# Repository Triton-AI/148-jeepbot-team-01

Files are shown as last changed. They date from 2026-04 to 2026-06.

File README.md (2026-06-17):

# 🚗 JeepBot | ECE/MAE 148 — Team 01

PowerWheels Jeep converted into a modular robotics platform for autonomous vehicle development, hardware integration, and controls experimentation.

Developed through UC San Diego ECE/MAE 148 in collaboration with Triton AI.

---

## ⚡ Overview

JeepBot is designed as a scalable and reproducible robotics platform combining:

- Raspberry Pi 5 for onboard computing and control
- VESC motor controllers for vehicle actuation
- OAK-D cameras for computer vision
- LiDAR and additional sensors for autonomous navigation
- ExpressLRS controller integration for manual control and testing

The project combines electrical integration, embedded systems, mechanical design, and software development.

---

## 🔧 Hardware Development

A major focus of this project was creating a clean, organized, and maintainable electronics architecture.

The system went through multiple hardware iterations:

### Version 1

- Initial full-scale architecture
- Designed around 5 VESC motor controllers
- More complex wiring system supporting multiple independent vehicle subsystems

### Version 2

- Simplified architecture using 2 VESC motor controllers
- Reduced wiring complexity
- Improved reliability and maintainability
- Redesigned to make the platform easier for future robotics students to reproduce, debug, and expand

The Version 2 redesign prioritizes accessibility while keeping the system expandable for future development.

Documentation for both versions:

`docs/version1/`

`docs/version2/`

---

## 📡 ELRS Controller Integration

The project includes development of a RadioMaster ExpressLRS controller interface for JeepBot testing and operation.

This allows manual control and testing during the development process while supporting future autonomous features.

Documentation and implementation:

`docs/elrs_controller/`

---

## 🧠 System Architecture

Control pipeline:

ExpressLRS Controller  
↓  
Receiver  
↓  
Raspberry Pi 5  
↓  
VESC Motor Controllers  
↓  
Motors / Steering  

Sensor pipeline:

OAK-D Cameras + LiDAR  
↓  
Raspberry Pi 5  
↓  
Autonomous Processing Stack  

---

## 📂 Repository Structure

CAD/

- electronics/
- mechanical/
- sensors/

docs/

- setup/
- version1/
- version2/
- elrs_controller/

src/

- jeepbot/
- camera/
- tests/

---

## 📚 Documentation

Technical documentation includes:

- Wiring diagrams
- Hardware revisions
- Raspberry Pi setup
- DepthAI/OAK-D setup
- ELRS controller integration
- Mechanical and electrical references

Main documentation:

`docs/`

---

## 🚧 Current Development Status

Completed:

✅ Vehicle hardware assembly  
✅ Electronics mounting and organization  
✅ VESC setup and configuration  
✅ Hardware architecture redesign (Version 1 → Version 2)  
✅ Documentation consolidation  

Ongoing:

- Continued software integration
- Sensor integration and testing
- Autonomous control development
- Future expansion toward the original 5-VESC architecture

---

## 👥 Team

ECE/MAE 148 — UC San Diego  
Triton AI

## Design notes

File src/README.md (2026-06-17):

# Source Code

This folder contains the main JeepBot software components.

## Structure

- `camera/`  
  Camera and depth perception code (OAK-D / DepthAI).

- `jeepbot/`  
  Vehicle control software including:
  - VESC control
  - controller interfaces
  - training scripts
  - perception integration
  - web interface tools

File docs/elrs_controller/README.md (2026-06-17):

# JeepBot ELRS Controller

Turn a RadioMaster **ExpressLRS** radio into a plug-and-play **USB joystick** for
DonkeyCar. An Arduino Leonardo reads the ELRS receiver's serial stream, filters and
decodes every stick / switch / button, and re-presents the whole thing to a Raspberry
Pi as a standard USB HID game controller at `/dev/input/js0`.

```
RadioMaster TX  ──2.4GHz──▶  RP4TD RX  ──serial @115200──▶  Arduino Leonardo  ──USB HID──▶  Raspberry Pi / DonkeyCar
```

## 📖 Setup guide

**Full step-by-step documentation:**
👉 **https://<your-username>.github.io/JeepBot-ELRS-Controller/**

It covers flashing the transmitter and receiver (ELRS Configurator v4.0.1, binding
phrase `JEEPBOT`), wiring the receiver to the Leonardo, building the firmware, the
DonkeyCar integration, the full channel map, and troubleshooting.

## Quick start

```bash
git clone https://github.com/<your-username>/JeepBot-ELRS-Controller.git
cd JeepBot-ELRS-Controller

pio run                      # build for the Arduino Leonardo
pio run --target upload      # flash it (board connected over USB)
```

All required libraries (`Joystick`, `FUTABA_SBUS`, `Streaming`) are vendored in
`lib/`, so there is nothing else to install beyond [PlatformIO](https://platformio.org/).

## Repo layout

| Path | What it is |
|---|---|
| `src/main.cpp` | Firmware: SBUS → filtered USB-HID joystick |
| `src/utils/` | Rolling-average `SBusTracker` helper |
| `lib/` | Bundled Arduino libraries (Joystick, FUTABA_SBUS, Streaming) |
| `donkeycar_joystick/my_joystick.py` | DonkeyCar controller part that maps the joystick to driving actions |
| `platformio.ini` | Build config (targets `leonardo`) |
| `docs/` | The setup-guide website (served by GitHub Pages) |

## Debug logging

Serial output is **off by default**, because on the Leonardo the debug Serial can
conflict with the USB-HID interface. To watch raw channel values while testing,
enable the build flag — then turn it back off for normal use:

```ini
[env:leonardo]
build_flags = -DDEBUG_LOG
```

## Hardware

- RadioMaster Pocket (internal 2.4 GHz, EdgeTX) — transmitter
- RadioMaster RP4TD True-Diversity 2.4 GHz — receiver
- Arduino Leonardo (ATmega32U4; USB-HID capable — an Uno will **not** work)
- Raspberry Pi running DonkeyCar

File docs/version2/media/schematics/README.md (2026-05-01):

# Schematics

This folder contains system-level and subsystem schematics for Version 2.

## Files
- system_schematic_v2.png → main system diagram

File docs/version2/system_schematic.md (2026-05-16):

# System Schematic

## Overview
This diagram represents the full system architecture, including power, control, actuation, and sensors.

---

## Interactive Version
🔗[Open Editable Schematic (SharePoint)](https://ucsdcloud-my.sharepoint.com/:u:/r/personal/hrubim_ucsd_edu/Documents/Drawing.vsdx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)

---

## Static View

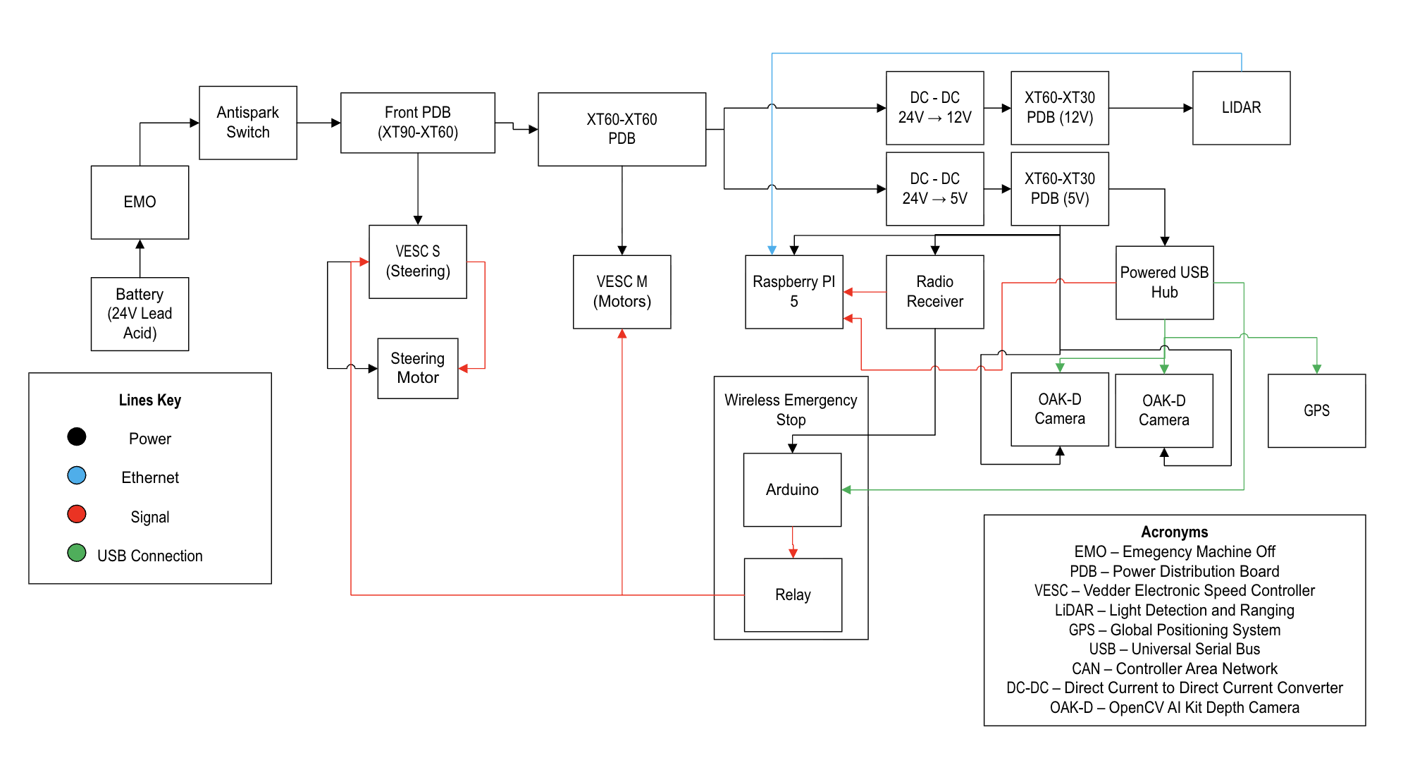
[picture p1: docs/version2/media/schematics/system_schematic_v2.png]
System Schematic


---

## Static With Components

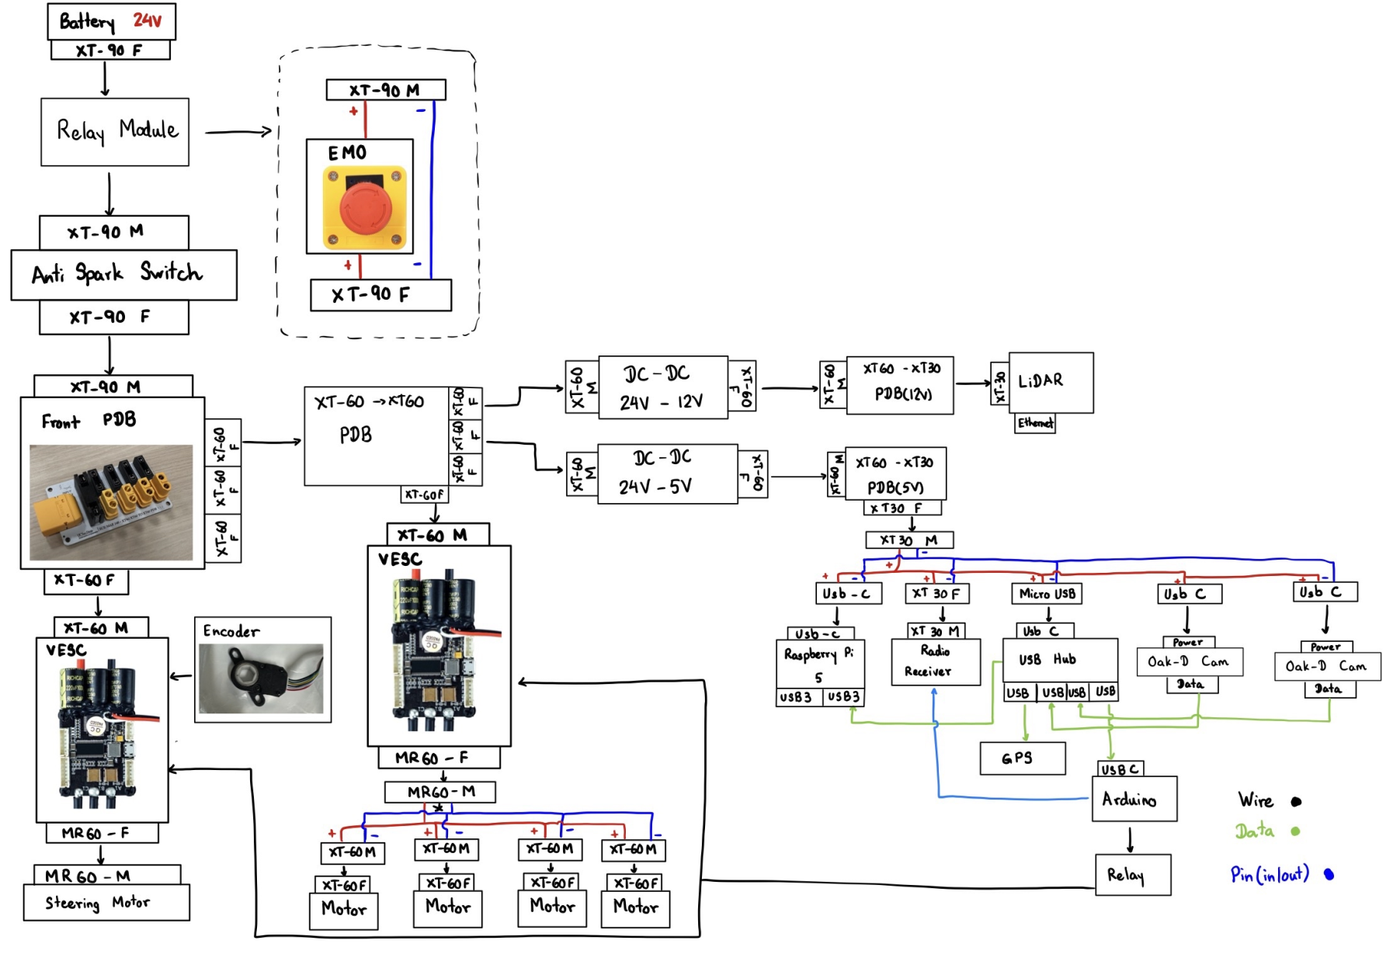
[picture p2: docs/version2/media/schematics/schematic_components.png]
System Schematic With Components


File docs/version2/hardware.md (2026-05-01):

# Hardware

## Core Components

### Power System
- 24V Lead Acid Battery
- EMO (Emergency Stop switch)
- Antispark Switch
- Power Distribution Board (PDB)

### Motor Control
- VESC (Motor Controller)
- VESC (Steering Controller)

### Compute
- Raspberry Pi 5
- Arduino (safety + relay control)

### Sensors
- 2x OAK-D Cameras
- LiDAR
- GPS Module

### Supporting Components
- DC-DC converters (24V → 12V, 5V)
- Powered USB Hub
- Wiring harness (12 AWG power lines)

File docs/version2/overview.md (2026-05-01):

# Overview

This system is a modified PowerWheels Jeep platform designed for robotics development.

The architecture is centered around a 24V power system with distributed control, sensing, and computation. The system integrates motor control (VESC), onboard computing (Raspberry Pi 5), sensor fusion (OAK-D cameras, LiDAR, GPS), and a safety layer with emergency stop functionality.

## High-Level Flow

Battery → EMO → Antispark → PDB → Subsystems

- Power is distributed to:
  - Motor controllers (VESC)
  - DC-DC converters (12V and 5V)
- Raspberry Pi acts as the central compute node
- Arduino handles safety and emergency stop logic
- Sensors feed data through USB and communication interfaces

This modular architecture allows easy debugging, expansion, and subsystem isolation.

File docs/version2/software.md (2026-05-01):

# Software

## Architecture

The system is structured around a central processing node (Raspberry Pi) and modular subsystems.

## Main Components

- Camera module:
  - Depth sensing
  - RGB capture
  - Dual OAK-D support

## Execution

Entry point:
src/main.py

Modules:
- camera/
- tests/

## Responsibilities

- Raspberry Pi:
  - Sensor processing
  - Decision making

- Arduino:
  - Emergency stop logic
  - Relay control

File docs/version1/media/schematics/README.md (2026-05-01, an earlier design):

# Schematics

This folder contains system-level and subsystem schematics for Version 1.

## Files
- system_schematic_v1.png → main system diagram

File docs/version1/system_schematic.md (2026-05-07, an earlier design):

# System Schematic (Version 1)

## Overview
This diagram represents the initial system architecture before simplification.

---

## Interactive Version
🔗 [Open Editable Schematic (SharePoint)](https://ucsdcloud-my.sharepoint.com/:u:/g/personal/hrubim_ucsd_edu/IQCxfeaB-xmnSrFH_fL8HkIkAejA7a_xhp8tK149ex-IXM8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)

---

## Static View

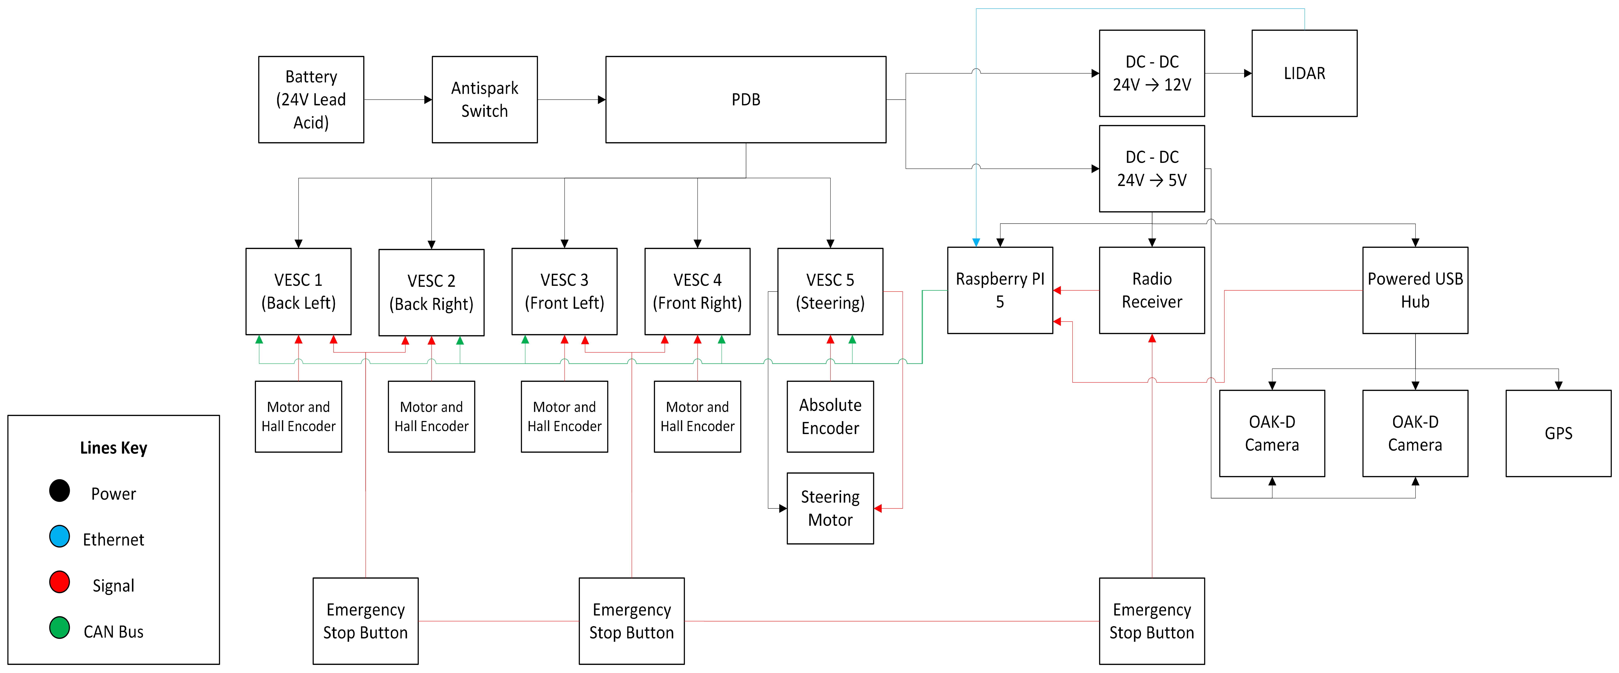
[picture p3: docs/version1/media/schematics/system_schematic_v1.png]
System Schematic


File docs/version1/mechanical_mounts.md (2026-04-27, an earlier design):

## 1. Overview

The mechanical system of the robot consists of custom-designed mounts used to securely attach sensors such as cameras and LiDAR to the jeep platform.

These mounts ensure:

- Stable sensor positioning  
- Consistent data collection  
- Proper alignment for perception systems  

Detailed CAD models, component breakdowns, and step-by-step installation instructions are provided in the full mounts documentation.

---

## 2. Full Mount Documentation

The complete mechanical design and installation guide is available in the following document:

**Document:** Jeepbot Mount Documentation  
**Author:** Keenai Braun  

Includes:

- CAD models for all mounts  
- Hardware requirements (screws, fasteners, components)  
- Detailed installation steps  
- Mounting configurations and variations  

---

## 3. Mounts Included in the System

### Front Camera Mount
- Holds the forward-facing OAK-D camera  
- Aligns with vehicle driving direction  

### Rear Camera Mounts (Two Configurations)

**Bar Mount**
- Attaches camera to structural bar  
- Uses clamp-based support  

**Ridge Mount**
- Positions camera higher on trunk  
- Improves rear perception  

### LiDAR Mount
- Secures LiDAR on top of vehicle  
- Enables 360° environmental scanning  

---

## 4. Mount Design Considerations

All mounts are designed to:

- Maintain rigid attachment during motion  
- Minimize vibration  
- Ensure correct orientation and field of view  
- Allow access for wiring and connections  

---

## 5. Installation Notes

- Follow the full documentation carefully  
- Some mounts may require cutting or drilling  
- Proper alignment is critical  
- Multiple iterations may be needed for best fit

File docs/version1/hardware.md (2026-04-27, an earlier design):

## 1. Hardware Architecture Overview

The robot hardware system is organized into three main layers:

- Power layer → provides energy to all components  
- Control layer → processes commands and controls movement  
- Sensor layer → collects environmental and system data  

Power flows from the battery through the Power Distribution Board (PDB), while the Raspberry Pi acts as the central controller.

---

## 2. Battery and Main Power System

The robot is powered by a 24V lead-acid battery:

- Voltage: 24V  
- Capacity: 7Ah  

**Power path:**  
Battery → Antispark Switch → Power Distribution Board (PDB)

- Antispark switch prevents inrush current  
- PDB distributes power and provides fuse protection  

---

## 3. Power Distribution

Power from the PDB is distributed to:

- VESC motor controllers  
- DC-DC converters  
- Onboard electronics  

**Voltage regulation:**

- 24V → motors (via VESCs)  
- 24V → 12V → LiDAR  
- 24V → 5V → Raspberry Pi, USB hub, sensors  

---

## 4. Wiring

Silicone insulated stranded wire is used for:

- Flexibility  
- Heat resistance  
- Vibration tolerance  

**Wire gauges:**

- 10 AWG → battery / high-current  
- 12 AWG → motors  
- 14–16 AWG → 5V electronics  
- 24 AWG → CAN bus  

---

## 5. Power Connectors

XT-series connectors are used:

- XT90 → battery  
- XT60 → distribution / converters  

Benefits:

- High current support  
- Reverse polarity protection  
- Strong connections  

---

## 6. Battery Power Cable

- 10 AWG silicone wire  
- Handles highest current in system  
- Connects battery → antispark → PDB  

---

## 7. Power Distribution Board (PDB)

The PDB:

- Distributes power to all subsystems  
- Connects VESCs and converters  
- Includes fuse protection  

Mounted inside the chassis.

---

## 8. Internal Wiring Layout

Connects:

- Motor controllers  
- Steering system  
- Encoders  
- Raspberry Pi  
- PDB  

Design goals:

- Minimize cable length  
- Reduce noise  
- Improve debugging access  

---

## 9. Motor Control System (VESC)

Five VESC controllers:

- VESC 1 → Back Left  
- VESC 2 → Back Right  
- VESC 3 → Front Left  
- VESC 4 → Front Right  
- VESC 5 → Steering  

Controls:

- Speed  
- Torque  
- Direction  

---

## 10. Encoder System

### Motor Encoders (Hall-effect)

- Provide rotor position  
- Connected to VESC  
- Enable precise control  

### Steering Encoder

- AS5600 magnetic sensor  
- I2C communication  
- Measures steering angle  

### Additional Encoder

- REV Through Bore Encoder  
- High-resolution rotation sensing  

---

## 11. Communication Interfaces

- CAN Bus → VESC network  
- USB → cameras, GPS (via hub)  
- I2C → steering encoder  
- Radio → RC → Pi  

---

## 12. Raspberry Pi (Main Controller)

Raspberry Pi 5 handles:

- Control logic  
- Communication with VESCs  
- Sensor data processing  

Connected to:

- CAN HAT  
- USB hub  
- Cameras  
- GPS  
- Radio receiver  

---

## 13. Sensors

- 2× OAK-D cameras → vision  
- LiDAR → mapping  
- GPS → localization  
- Encoders → motion + steering  

---

## 14. Physical Layout

- Battery → rear  
- PDB → center  
- Pi → communication hub  
- VESCs → near motors  
- Sensors → external  

Improves:

- Weight distribution  
- Wiring efficiency  
- Accessibility  

---

## 15. Emergency Stop System

- Multiple emergency stop buttons  
- Interrupt motor control signals  
- Immediately stop motion  

---

## 16. Safety and Best Practices

- Disconnect battery before working  
- Verify polarity  
- Avoid shorts on PDB  
- Secure all connections  
- Keep emergency stops accessible  

---

## 17. Current Limitations

- Wiring organization can improve  
- Cable management incomplete  
- Some components exposed  
- Steering encoder not fully integrated  
- Layout may change during development

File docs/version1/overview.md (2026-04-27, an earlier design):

# Documentation Overview

This documentation provides a complete overview of the Jeep robot system, including hardware, software, control, and system integration.

Each section is organized to guide the reader from a high-level understanding of the system to detailed implementation and troubleshooting.

## Sections

### Overview
Provides a general introduction to the robot system, including its purpose, main components, and overall architecture.

### Current Status
Describes the current state of the project, including what is working, what is incomplete, and known issues.

### Hardware
Details all physical components of the system, including power distribution, wiring, motor controllers, sensors, and connections.

### Mechanical (Mounts)
Documents all mechanical structures and 3D-printed mounts used to hold sensors and components in place.

### Software & Control
Covers the software architecture, Raspberry Pi setup, communication with VESC controllers, and control logic.

### Setup Guide
Step-by-step instructions for setting up and running the system from scratch.

### Troubleshooting
Lists common issues, known problems, and solutions to help debug the system.

### Media
Contains images and visual documentation of the robot, components, wiring, and system setup.

### Bill of Materials (BOM)
Lists all components used in the project, including parts, specifications, and references.

### Progress & Logs
Tracks the development timeline, key milestones, and ongoing updates to the project.

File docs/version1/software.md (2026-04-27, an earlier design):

## 1. Software Overview

The robot uses a Raspberry Pi 5 as the main computer responsible for system control, communication, and data processing.

The software system handles:

- Receiving user input (RC controller / teleoperation)  
- Sending commands to motor controllers (VESCs)  
- Reading and processing sensor data  
- Managing communication between system components  

This architecture enables centralized control while remaining modular for future upgrades.

---

## 2. Control Flow

**Primary control path:**

User Input → Radio Receiver → Raspberry Pi → CAN Bus → VESC → Motors

**Sensor data flow:**

Sensors → Raspberry Pi → Data Processing / Logging

The Raspberry Pi translates inputs into motor commands and collects sensor data.

---

## 3. Teleoperation

Teleoperation enables manual control during development.

### RC Controller (Primary Method)
RC → Receiver → Raspberry Pi → CAN → VESC → Motors

- Low latency  
- High reliability  
- No internet required  

### ROS2 Teleoperation (Future)
Laptop → WiFi → Raspberry Pi → CAN → VESC

- Integrates sensor data  
- Enables autonomy development  

### Web Dashboard (Optional)
Web → WiFi → Raspberry Pi → Motors

- Simple control interface  
- Displays sensor data  

### Strategy

- RC Controller → primary control  
- ROS2 → advanced/autonomous control  
- Web dashboard → visualization  

---

## 4. Sensor Data Handling

Connected sensors:

- OAK-D cameras  
- LiDAR  
- GPS (pending)  
- Motor encoders  

Used for:

- System monitoring  
- Data collection  
- Future autonomy  

Processing is done locally on the Raspberry Pi.

---

## 5. Running the System (Basic)

- Power on system  
- Connect to Raspberry Pi (SSH / NoMachine)  
- Run control software  
- Drive using RC controller  

*Commands will be added once finalized.*

---

## 6. Future Development

Planned improvements:

- Autonomous navigation  
- Sensor fusion  
- Obstacle detection  
- Path planning  
- Improved CAN control  
- Full Pi ↔ VESC integration

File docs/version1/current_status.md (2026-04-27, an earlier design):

## 1. Overview

The system is fully assembled mechanically but is currently non-operational due to hardware and software integration issues.

---

## 2. What Is Working

- All components are mounted on the jeep  
- Four drive VESCs are fully configured and tested with motors and encoders  
- CAN communication between VESCs works when tested independently (daisy-chain)  
- Raspberry Pi is mounted and includes a CAN HAT  
- Encoder mounts are properly installed and functional  
- Motor encoders are wired and working  

---

## 3. What Is Not Working

### 3.1 Power System
- The antispark switch is broken and does not interrupt power  
- The system powers on immediately when the battery is connected, which is unsafe  
- One of the PDB fuses is missing or broken  
- This issue is related to a broken connector in the LiDAR power line  
- Path affected: PDB → 12V DC-DC converter → LiDAR  
- The corresponding PDB output does not activate (no indicator light)  
- LiDAR is not receiving power  

### 3.2 Control and Movement
- The robot does not move  
- Raspberry Pi is not yet integrated with the VESC network for control  
- CAN communication between the Raspberry Pi and VESC network has not been implemented  
- Motor controllers work individually but are not integrated into the full system  

### 3.3 Steering System
- Steering VESC (VESC 5) is installed and connected  
- Steering encoder is not connected to the VESC  
- Current encoder is not directly compatible with VESC input  
- Alternative integration or different encoder is required  
- Steering is not functional due to lack of encoder feedback  

### 3.4 Sensors
- Front and rear cameras are mounted but not connected to the USB hub  
- Front camera needs a longer USB cable  
- Rear camera is not connected  
- LiDAR is installed but not powered  
- GPS module is not installed  

### 3.5 Wiring and Integration
- 5V DC-DC converter cables are too short  
- 5V output not connected to Raspberry Pi or USB hub  
- CAN wiring between VESCs is complete  
- CAN not connected to Raspberry Pi CAN HAT  
- USB connections incomplete  

### 3.6 Emergency and Safety
- Emergency stop system is not connected  
- No hardware-level shutdown mechanism  
- System powers on immediately when battery is connected  
- This is a critical safety risk  

### 3.7 Software
- Raspberry Pi was reflashed — current state uncertain  
- Camera setup may need reconfiguration  
- VESC CAN control not implemented  
- Control software incomplete  
- System environment not validated  

---

## 4. Main Blocking Issues

- Broken antispark switch (unsafe power behavior)  
- No emergency stop system (no safe shutdown)  
- No CAN communication (Pi → VESCs)  
- Steering encoder not connected / incompatible  
- LiDAR power failure (PDB fuse / connector issue)  
- Critical 5V and USB connections incomplete

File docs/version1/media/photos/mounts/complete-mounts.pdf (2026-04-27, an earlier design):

## Jeepbot: Mount Documentation

## Keenai Braun

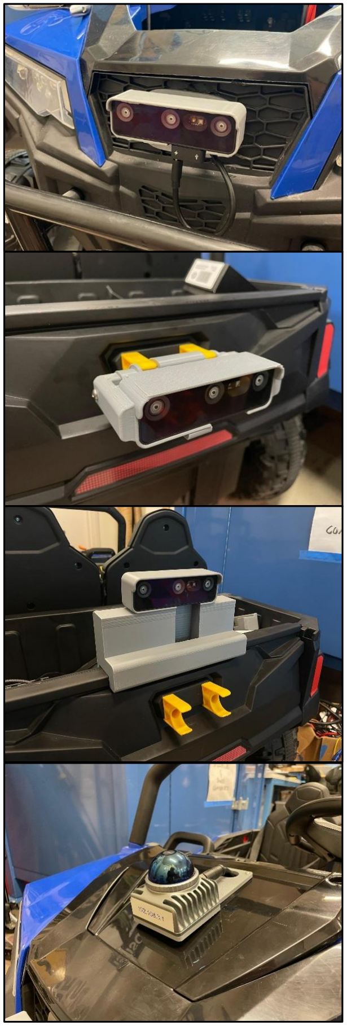
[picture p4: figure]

2 | P a g e

Table of Contents

### 1 MOUNTS | 3

### 1.1 OVERVIEW | 3 1.2 FRONT CAMERA MOUNT | 7 1.3 REAR CAMERA MOUNTS | 15

1.3.1 BAR MOUNT - VARIATION 1 | 15
1.3.2 RIDGE MOUNT - VARIATION 2 | 21

### 1.4 LIDAR MOUNT | 23

Table of Figures

Figure 1: CAD Assembly of Front Camera Mount | 3
Figure 2: CAD Assembly of Rear Camera Mount (Bar Mount - Variation 1) | 4
Figure 3: CAD Assembly of Rear Camera Mount (Ridge Mount - Variation 2) | 5
Figure 4: CAD of LIDAR Mount | 6
Figure 5: Front Camera Mount | 7
Figure 6: Front Camera Cap | 8
Figure 7: Dual Mount – Camera and PDB | 9
Figure 8: Rear Camera Mount | 15
Figure 9: Trunk Bar | 16
Figure 10: Trunk Bar Support | 17
Figure 11: Ridge Mount | 21
Figure 12: LIDAR Mount | 23

Revision History

Author | Revision | Comment
Keenai Braun | 15th March, 2026 (Rev. 1.0) | Initial Draft
Keenai Braun | 17 th March, 2026 (Rev. 2.0) | Final submission

## 1 Mounts

There are a total of three external mounts on the Jeepbot – front camera, rear camera, and LIDAR. The rear camera has two mounting variations: bar mount and ridge mount. In this section, you will find an overview of the four mount assemblies with the individual components that make up each one. Next, you will see the individual components per mount configuration along with the additional parts needed for each one during installation. Finally, you will see a sequence of installation steps and photos to help guide you with your installation process.

1.1 Overview

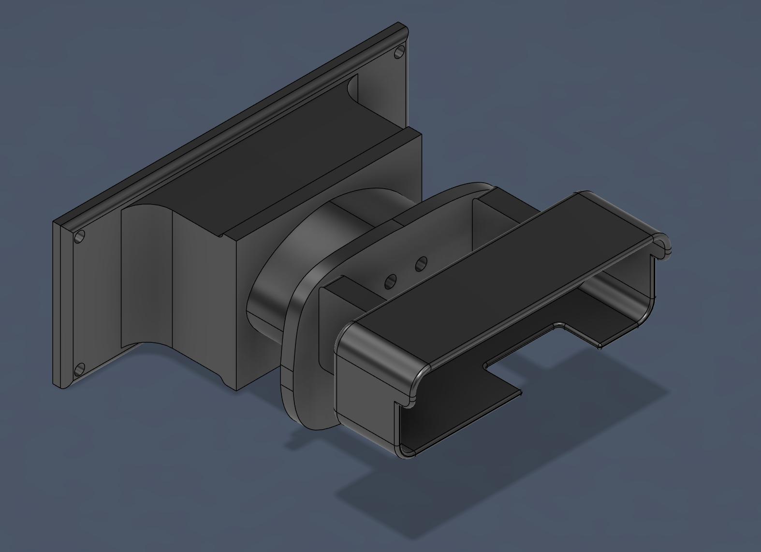
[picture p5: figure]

Figure 1: CAD Assembly of Front Camera Mount

Components
1) Front Camera Mount
2) Front Camera Cap
3) Dual Mount – Camera and PDB

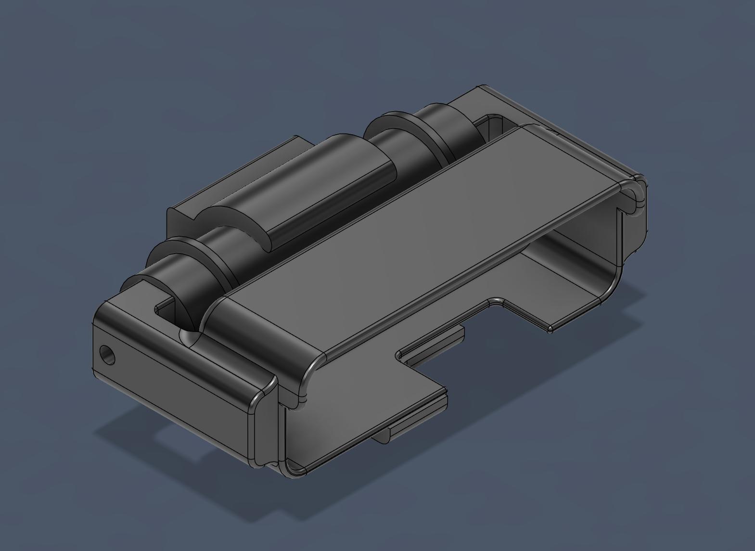
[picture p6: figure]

Figure 2: CAD Assembly of Rear Camera Mount (Bar Mount - Variation 1)

Components
1) Rear Camera Mount
2) Trunk Bar
3) Trunk Bar Support

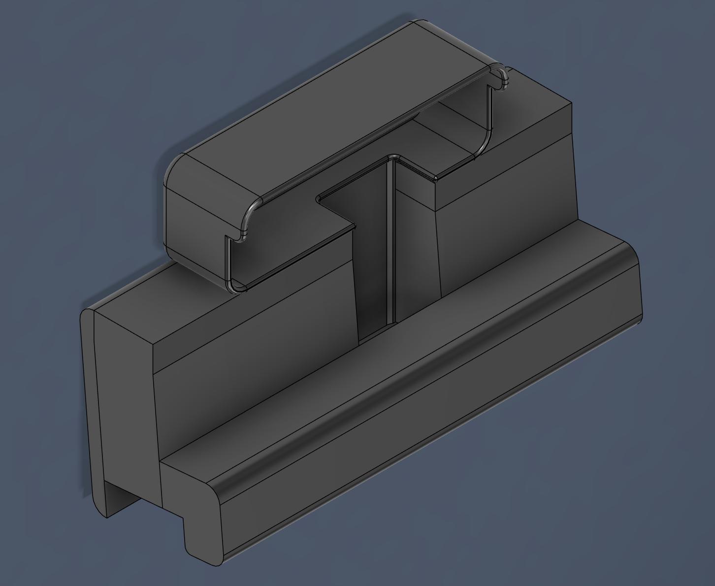
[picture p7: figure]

Figure 3: CAD Assembly of Rear Camera Mount (Ridge Mount - Variation 2)

Components

1) Ridge Mount

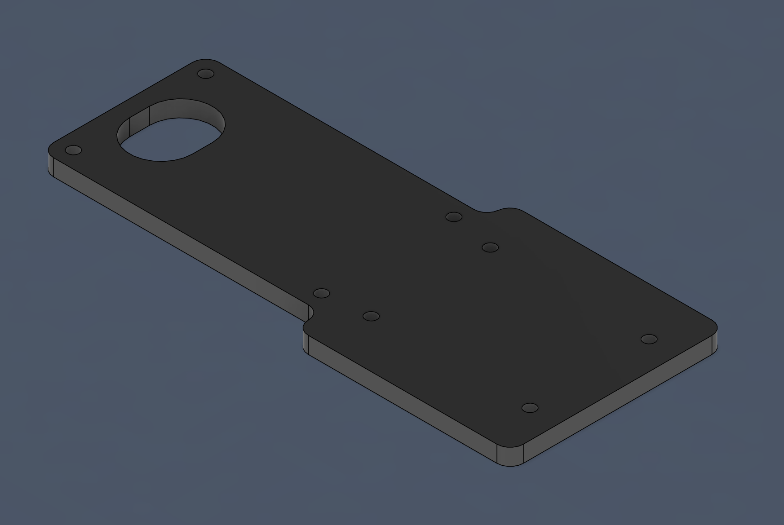
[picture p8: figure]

Figure 4: CAD of LIDAR Mount

Components

1) LIDAR Mount

1.2 Front Camera Mount

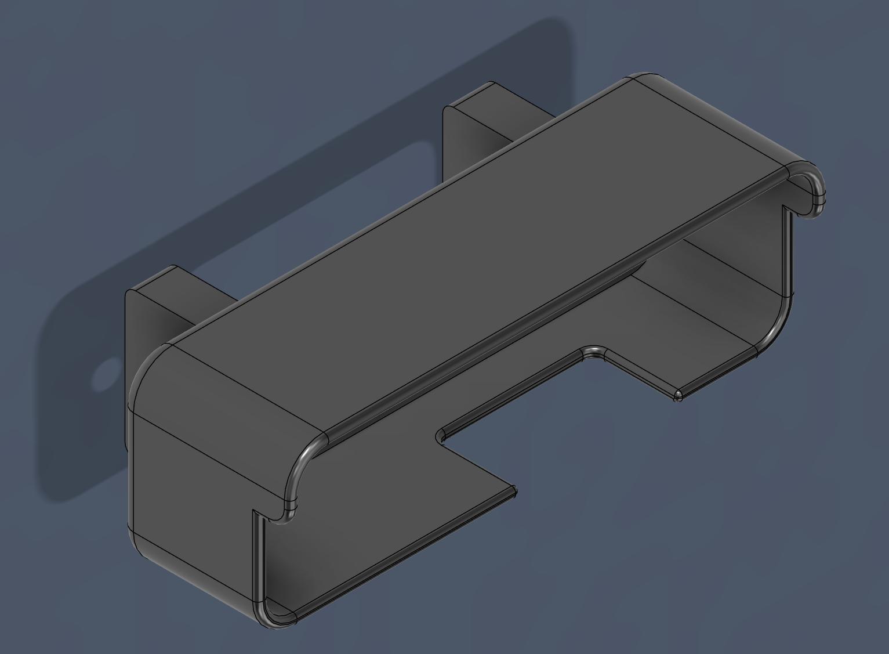
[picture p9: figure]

Figure 5: Front Camera Mount

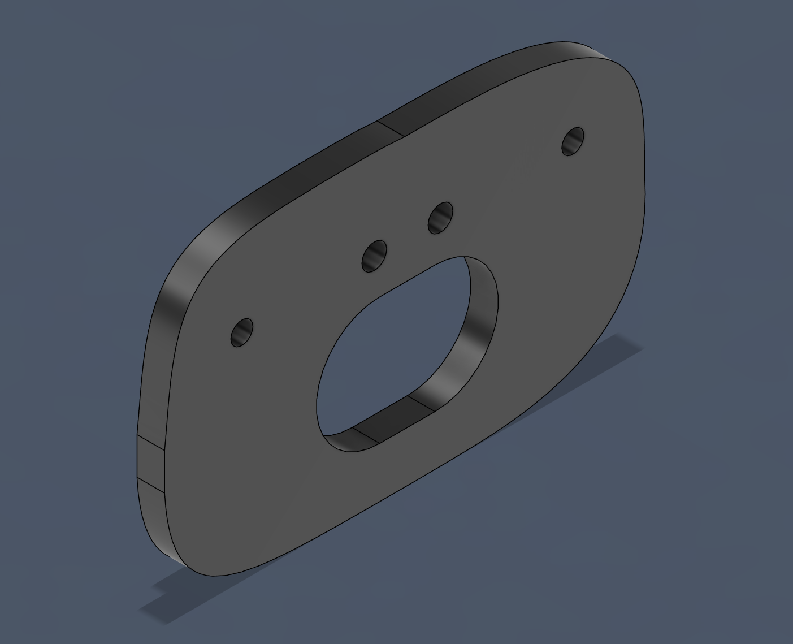
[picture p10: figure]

Figure 6: Front Camera Cap

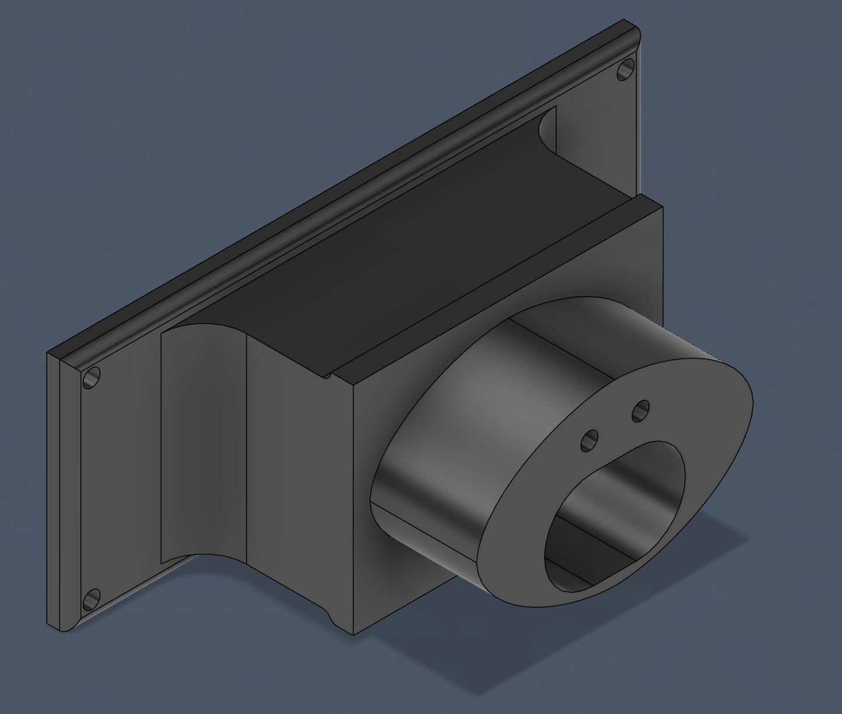
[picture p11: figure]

Figure 7: Dual Mount – Camera and PDB

Additional Parts

Front Camera Mount | Front Camera Cap | Dual Mount – Camera and PDB
2 x M4 Flathead Screws (Length: 25mm) | 2 x M4 Screws (Length: 25mm) | 4 x M4 Screws (Length: 6mm)
2 x M4 Screws (Length: 8mm) | 2 x M4 Washers

Before Installation

Note: You will need to make a hole in the front of the Jeep. In the example below, a Dremel was used to create the openings and even out the sides. In addition, the Dremel was quite unpredictable. In hindsight, a handsaw or using a device to melt the plastic (such as a soldering iron) could have been better options for achieving a cleaner, more accurate cut. If you encounter the problem of having an inaccurate hole that lines up with the Front Camera Cap, you will need to go into CAD and make a shape that will fit your hole (or edit the Front Camera Cap CAD). Ensure that the Front Camera Cap is snug to the Jeepbot. This process may take a few iterations to get right.

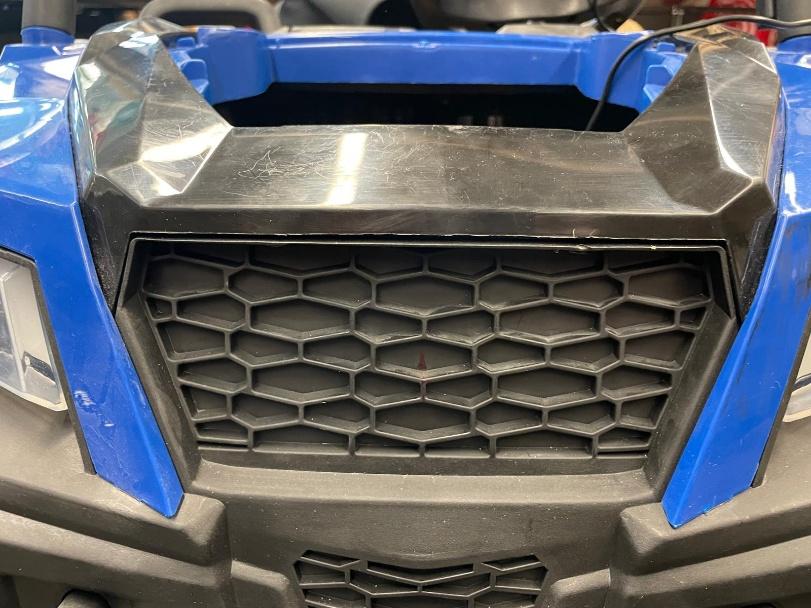
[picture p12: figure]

Front of Jeepbot before Dremel cutting

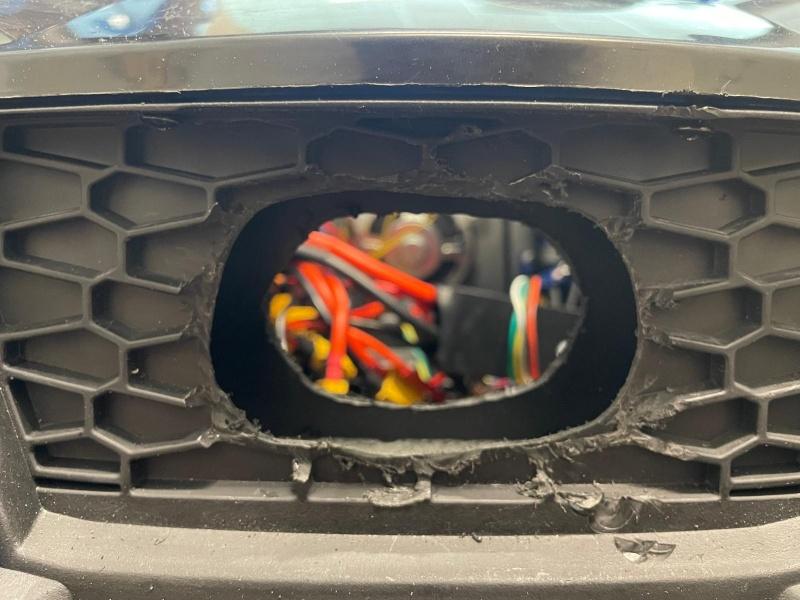
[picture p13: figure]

Front of Jeepbot after Dremel cutting

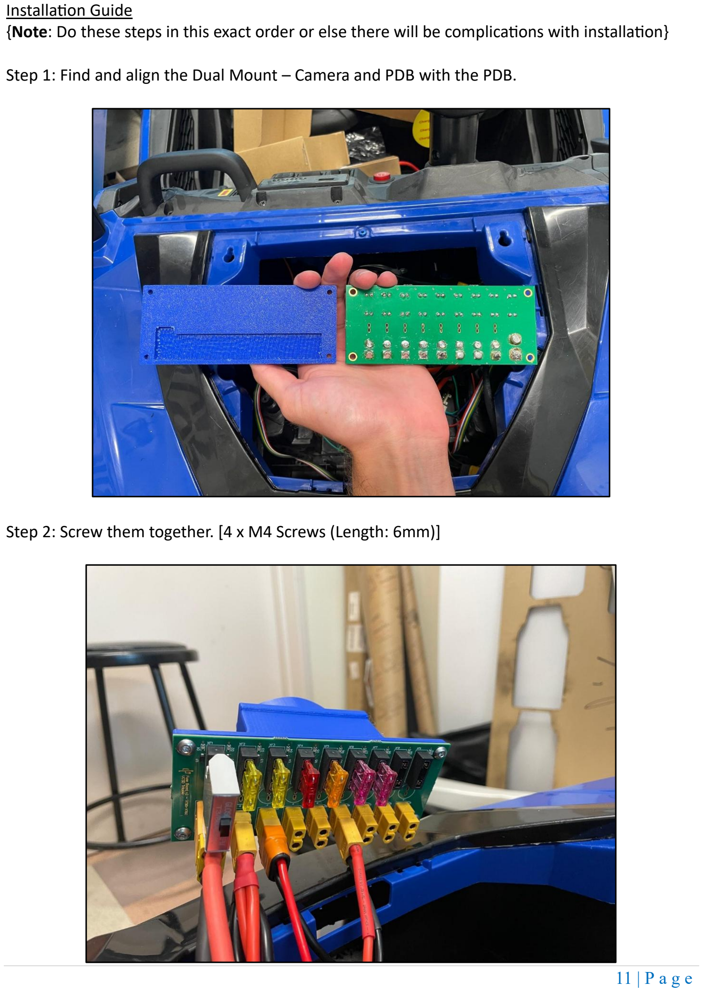
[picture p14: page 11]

Installation Guide
{Note: Do these steps in this exact order or else there will be complications with installation}
Step 1: Find and align the Dual Mount – Camera and PDB with the PDB.
Step 2: Screw them together. [4 x M4 Screws (Length: 6mm)]

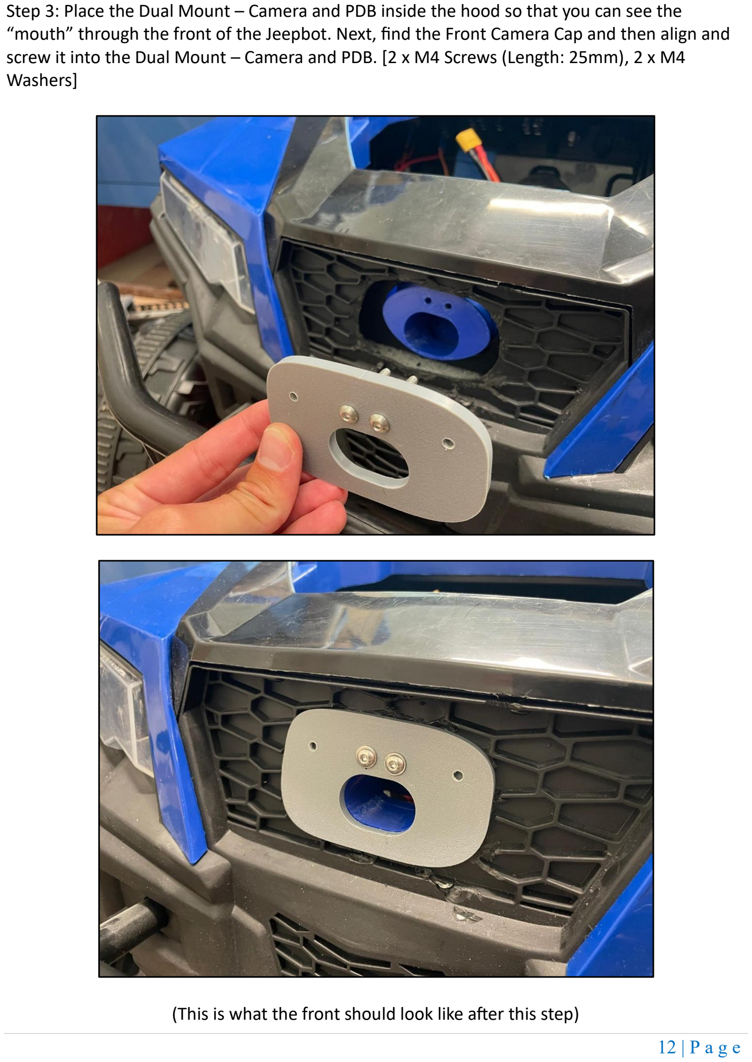
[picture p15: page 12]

Step 3: Place the Dual Mount – Camera and PDB inside the hood so that you can see the “mouth” through the front of the Jeepbot. Next, find the Front Camera Cap and then align and screw it into the Dual Mount – Camera and PDB. [2 x M4 Screws (Length: 25mm), 2 x M4 Washers]

(This is what the front should look like after this step)

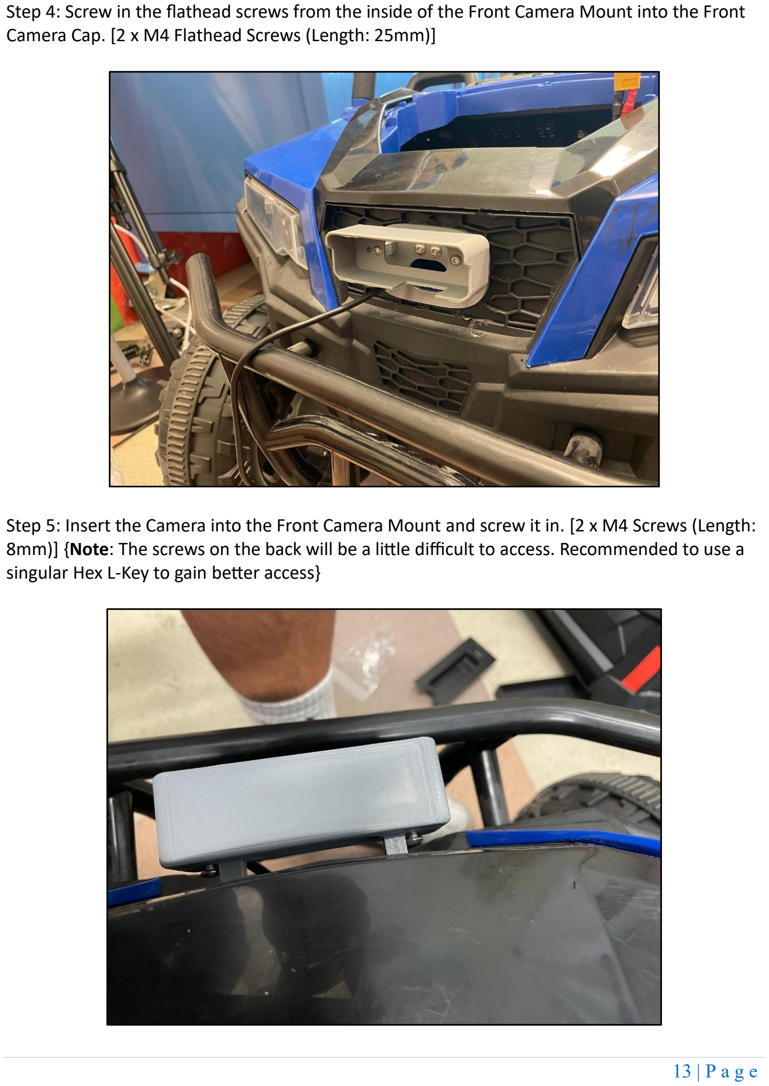
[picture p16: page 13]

Step 4: Screw in the flathead screws from the inside of the Front Camera Mount into the Front Camera Cap. [2 x M4 Flathead Screws (Length: 25mm)]
Step 5: Insert the Camera into the Front Camera Mount and screw it in. [2 x M4 Screws (Length: 8mm)] {Note: The screws on the back will be a little difficult to access. Recommended to use a singular Hex L-Key to gain better access}

Step 6: Funnel a USB-C wire from the inside hood through the Dual Mount – Camera and PDB and Front Camera Cap and attach to the Camera. Installation complete.

1.3 Rear Camera Mounts
1.3.1 Bar Mount - Variation 1

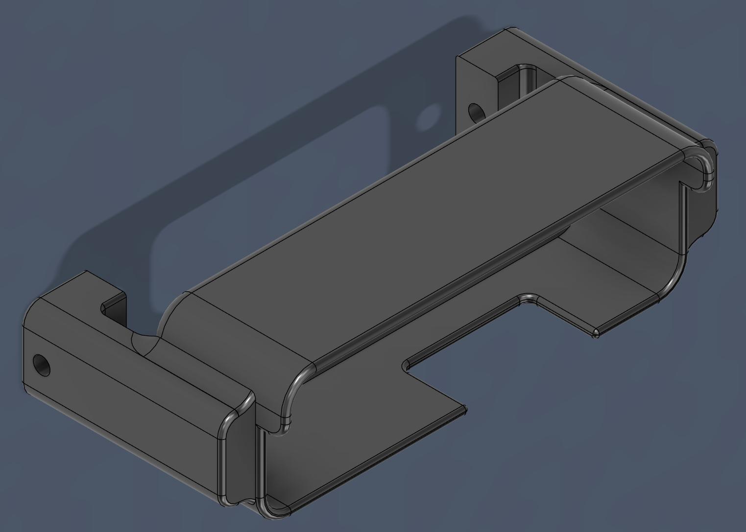
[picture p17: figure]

Figure 8: Rear Camera Mount

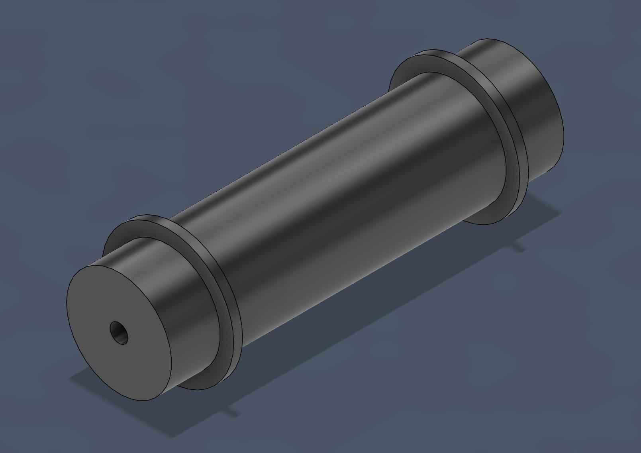
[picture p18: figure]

Figure 9: Trunk Bar

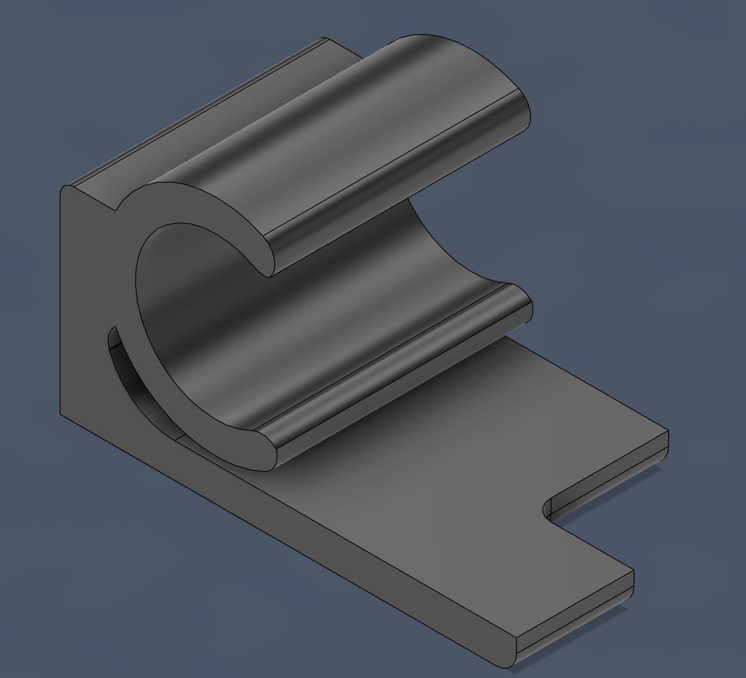
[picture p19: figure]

Figure 10: Trunk Bar Support

Additional Parts

Rear Camera Mount | Trunk Bar | Trunk Bar Support
2 x M4 Screws (Length: 25mm) | None | None

2 x M4 Screws (Length: 8mm)
2 x M4 Washers

Before Installation

Note: This mount was only made for use with the Jeepbot in open spaces without objects in view. Do not use this mount when driving indoors or near other objects, as the Camera will get damaged if the Jeepbot gets rear-ended. Recommended to use the Rear Camera Mount (Ridge Mount - Variation 2).

Installation Guide

Step 1: Place the Camera in the Rear Camera Mount and screw into place. [2 x M4 Screws (Length: 8mm)]

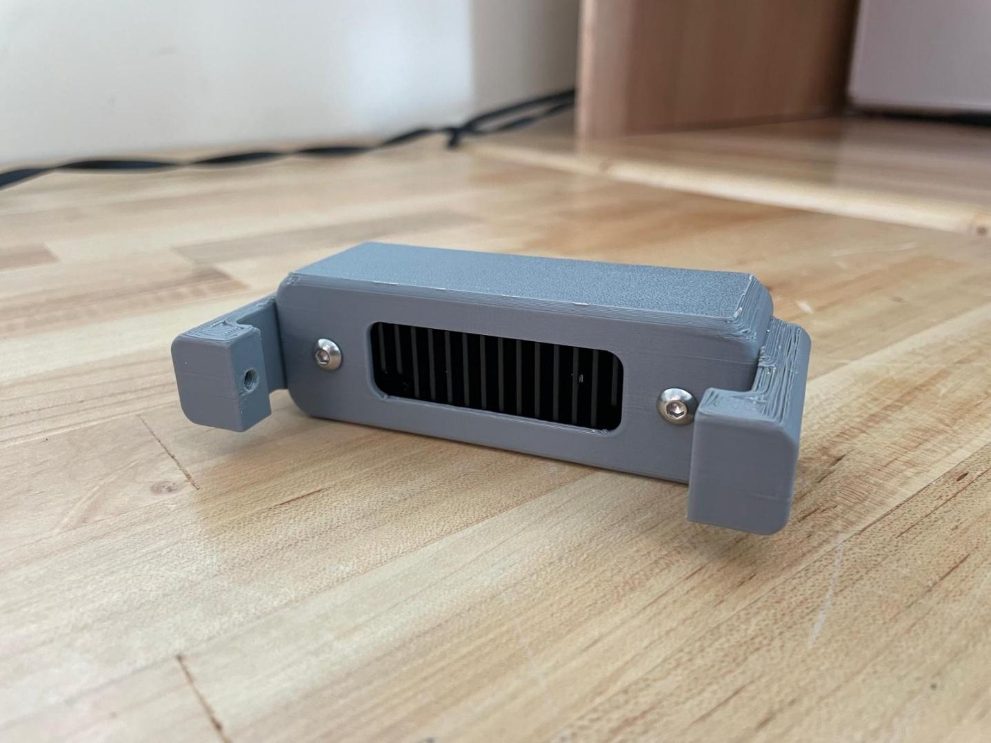
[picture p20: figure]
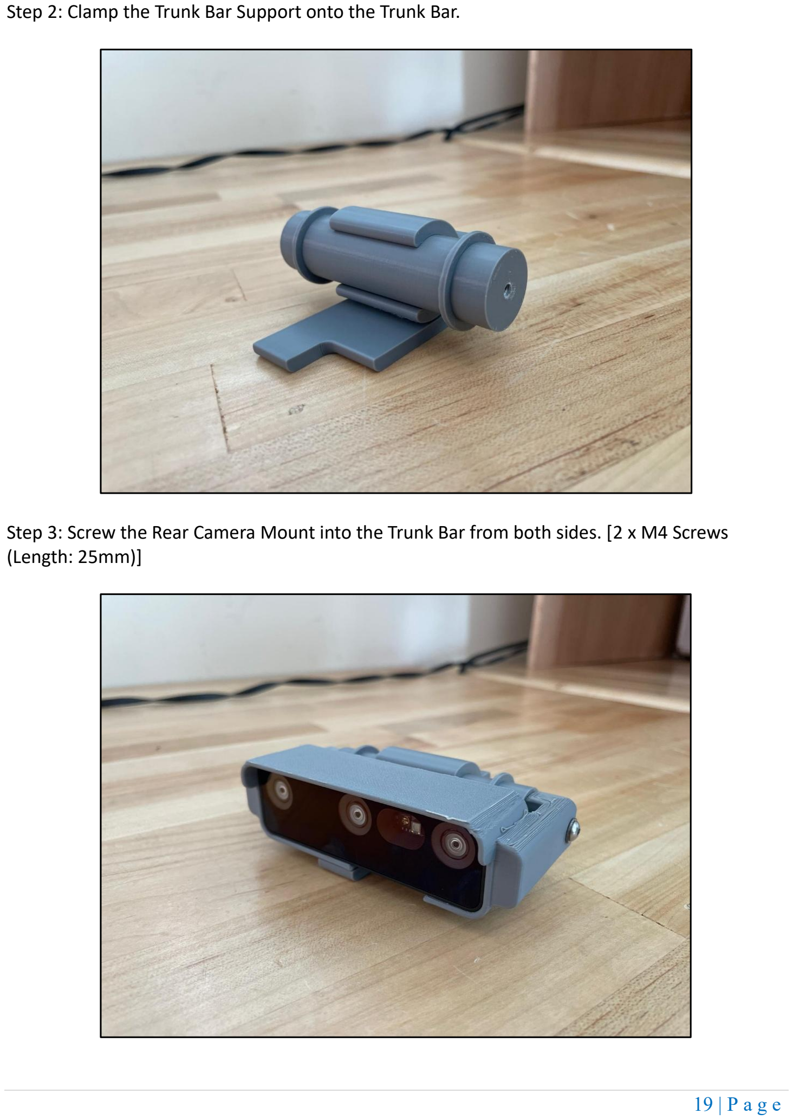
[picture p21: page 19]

Step 2: Clamp the Trunk Bar Support onto the Trunk Bar.
Step 3: Screw the Rear Camera Mount into the Trunk Bar from both sides. [2 x M4 Screws (Length: 25mm)]

Step 4: Insert the Bar Mount into the yellow clamps at the rear of the Jeepbot. The clamps should fit right in between the Trunk Bar Support and the Rear Camera Mount. Installation complete. {Note: This is a tight fit, do not be afraid to use a little force}

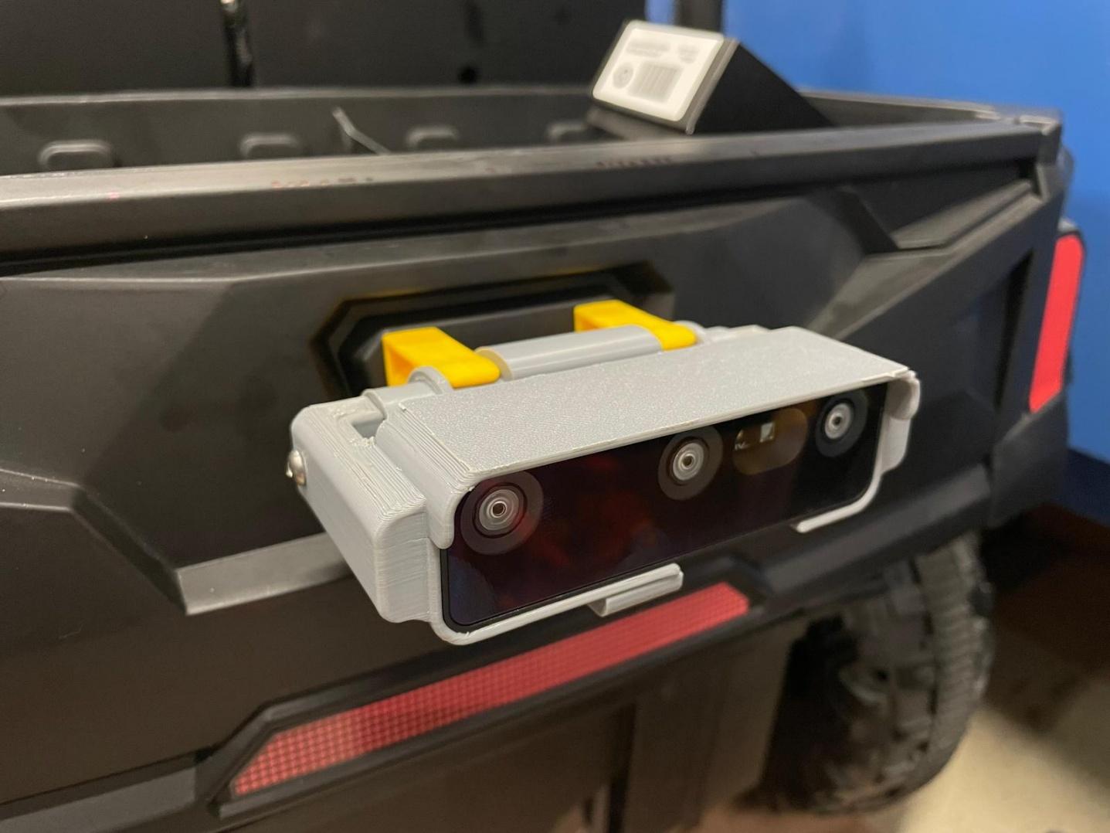
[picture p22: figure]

1.3.2 Ridge Mount - Variation 2

Figure 11: Ridge Mount

Additional Parts

Ridge Mount

2 x M4 Screws (Length: 8mm)

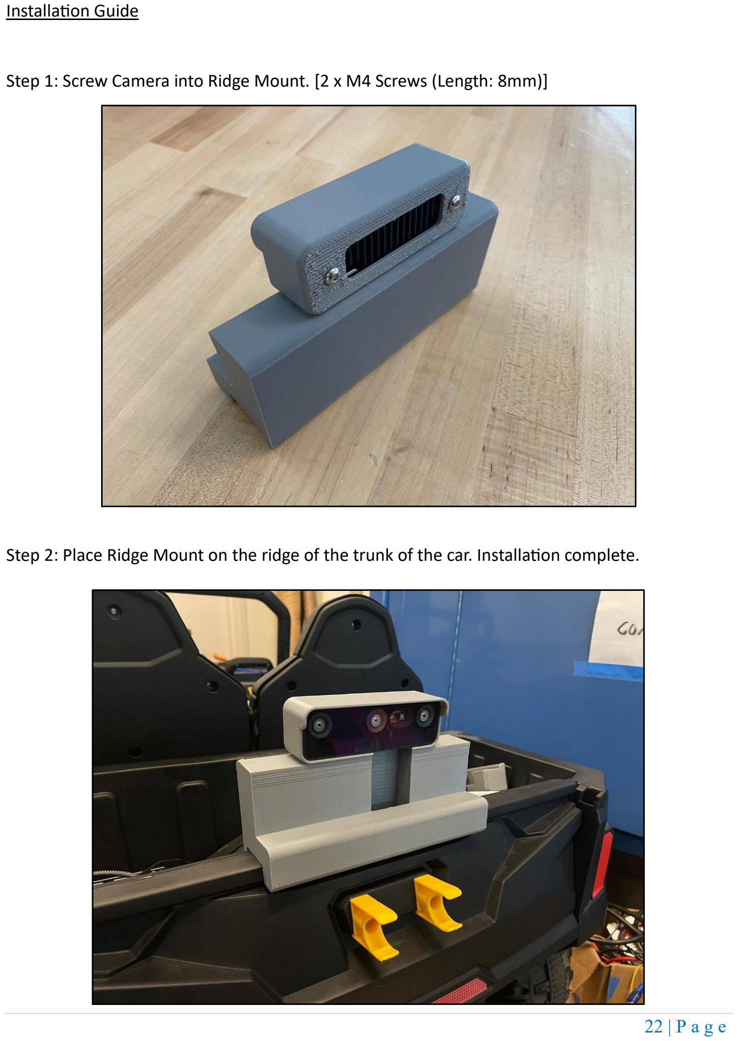
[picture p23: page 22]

Installation Guide

Step 1: Screw Camera into Ridge Mount. [2 x M4 Screws (Length: 8mm)]
Step 2: Place Ridge Mount on the ridge of the trunk of the car. Installation complete.

1.4 LIDAR Mount

Figure 12: LIDAR Mount

Additional Parts

LIDAR Mount
4 x M3 Flathead Screws (Length: 6mm) 4 x M3 Screws (Length: 15mm)
4 x M3 Washers
4 x M3 Nuts

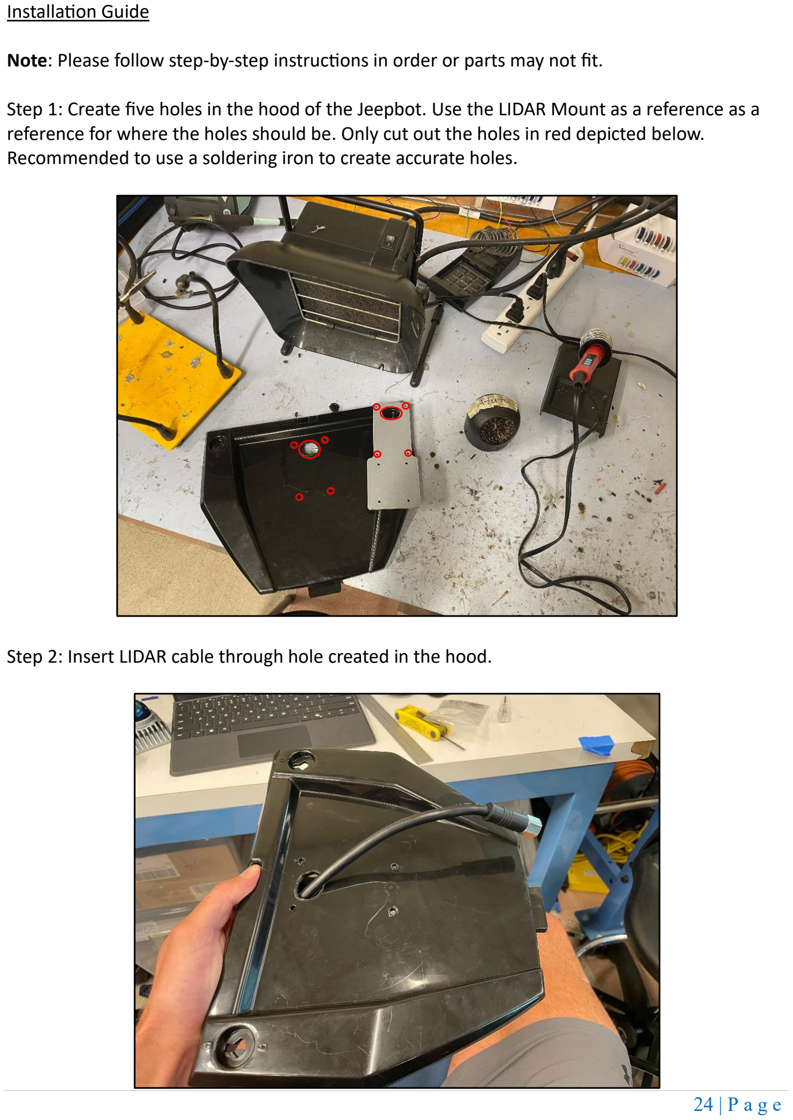
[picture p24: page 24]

Installation Guide

Note: Please follow step-by-step instructions in order or parts may not fit.

Step 1: Create five holes in the hood of the Jeepbot. Use the LIDAR Mount as a reference as a reference for where the holes should be. Only cut out the holes in red depicted below. Recommended to use a soldering iron to create accurate holes.
Step 2: Insert LIDAR cable through hole created in the hood.


Step 3: Insert LIDAR cable through the LIDAR Mount.
Step 4: Connect the LIDAR cable to the LIDAR. Make sure there is a snug connection.


Step 5: Screw in the flathead screws to the LIDAR through the bottom of the LIDAR Mount. [4 x M3 Flathead Screws (Length: 6mm)]
Step 6: Screw LIDAR Mount into the hood. Be sure to use the nuts at the bottom to ensure secure hold. [4 x M3 Screws (Length: 15mm), 4 x M3 Washers, 4 x M3 Nuts]


Step 7: Installation complete.

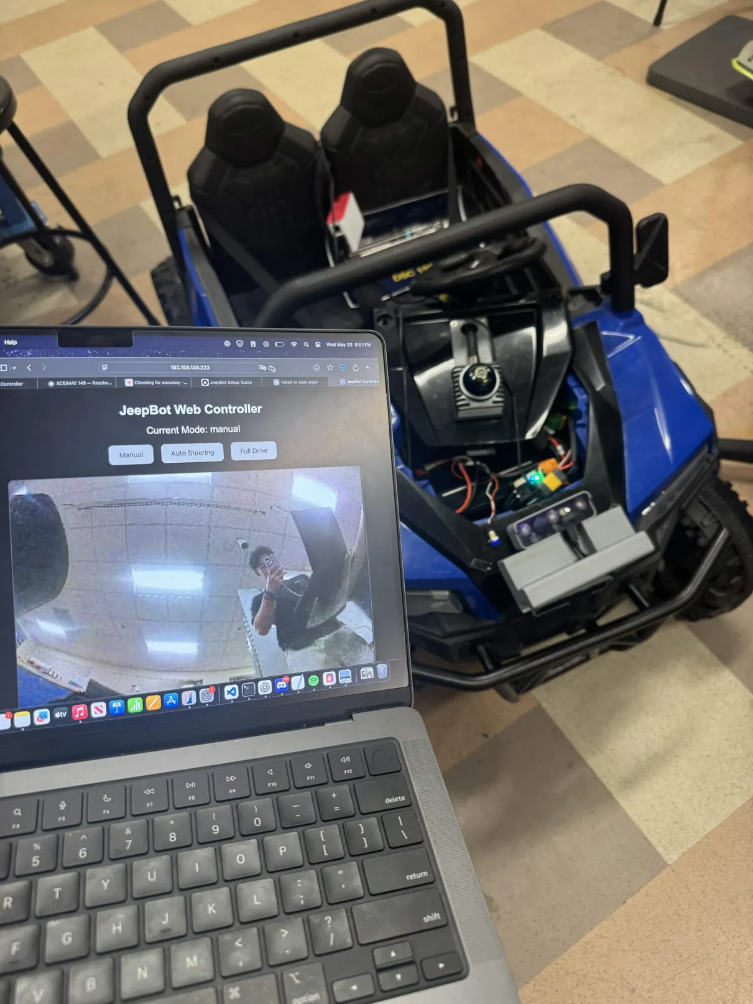
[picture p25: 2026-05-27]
docs/version2/media/photos/overview/overview_jeepbot_web_controller_live.jpg

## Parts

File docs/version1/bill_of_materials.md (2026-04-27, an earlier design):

## 1. Overview

This section lists the main hardware components used in the robot system.

The list includes core components required for:

- Power  
- Control  
- Sensing  
- Communication  

Additional mechanical components (mounts, screws, brackets) are documented in the Mechanical section.

---

## 2. Core Components

**Component — Quantity — Purpose**

- 24V lead-acid battery (7Ah) — 1 — Main power source  
- Antispark switch — 1 — Protects system during power connection (currently not functional)  
- Power Distribution Board (PDB) — 1 — Distributes power to all components  
- VESC motor controllers — 5 — Control drive motors and steering  
- Raspberry Pi 5 — 1 — Main computer and controller  
- CAN interface (CAN HAT) — 1 — Enables CAN communication with VESCs  
- DC-DC converters (24V → 12V, 5V) — 2+ — Regulate voltage  
- Powered USB hub — 1 — Connects and powers USB devices  

---

## 3. Sensors

**Component — Quantity — Purpose**

- OAK-D cameras — 2 — Depth perception and vision  
- LiDAR sensor — 1 — Environment mapping (currently not powered)  
- GPS module — 1 — Location tracking (not yet installed)  
- AS5600 magnetic encoder — 1 — Steering angle measurement  
- Motor encoders (hall-effect) — 4+ — Motor position feedback  

---

## 4. Wiring and Connectors

**Component — Quantity — Purpose**

- Silicone wire (10 AWG) — As needed — High-current battery wiring  
- Silicone wire (12 AWG) — As needed — Motor wiring  
- Silicone wire (14–16 AWG) — As needed — Low-voltage electronics  
- CAN bus wiring (24 AWG) — As needed — Communication between VESCs  
- XT90 connectors — As needed — Battery connections  
- XT60 connectors — As needed — Power distribution and DC-DC connections  

---

## 5. Notes

- Quantities are approximate and may change  
- Some components are not fully integrated or operational  
- Mechanical hardware is documented in the Mechanical section  
- Specific models and links can be added later

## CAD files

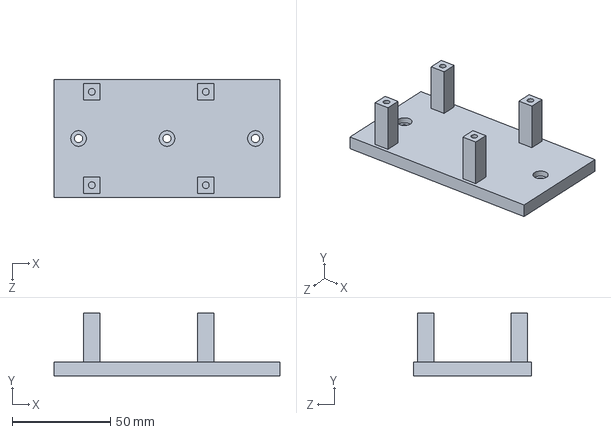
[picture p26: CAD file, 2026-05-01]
CAD/electronics/raspberry_pi/RPI Mount.SLDPRT
115.0 x 32.0 x 60.0 mm

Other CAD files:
CAD/electronics/encoder/Encoder Mount.f3d
CAD/mechanical/mounting_plates/bottom mounting plate.f3d
CAD/mechanical/mounting_plates/trunk mounting plate.f3d
CAD/mechanical/trunk_lid/lid.f3d
CAD/sensors/front_camera/DUAL MOUNT - CAMERA AND PDB.f3d
CAD/sensors/front_camera/FRONT CAMERA CAP.f3d
CAD/sensors/front_camera/FRONT CAMERA MOUNT.f3d
CAD/sensors/front_camera/Front Camera Assembly.f3z
CAD/sensors/lidar/LiDAR MOUNT.f3d
CAD/sensors/rear_camera_bar_mount/REAR CAMERA MOUNT.f3d
CAD/sensors/rear_camera_bar_mount/Rear Camera Assembly.f3z
CAD/sensors/rear_camera_bar_mount/TRUNK BAR SUPPORT.f3d
CAD/sensors/rear_camera_bar_mount/TRUNK BAR.f3d
CAD/sensors/rear_camera_ridge_mount/RIDGE MOUNT.f3d

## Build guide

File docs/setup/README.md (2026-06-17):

# JeepBot Setup Documentation

This folder contains setup references for the JeepBot platform.

## Files

- `raspberry_pi_setup.md` — Raspberry Pi setup notes
- `depthai_setup.md` — OAK-D / DepthAI setup notes
- `reference/` — additional setup reference files

## Related Code

Main JeepBot software is located in:

`src/jeepbot/`

Key files include:

- `jeepbot_drive.py`
- `camera.py`
- `yolo_detector.py`
- `pygame_f710.py`
- `pygame_radiomaster.py`
- `controller_profiles.py`

## Requirements

JeepBot-specific requirements are stored in:

`src/jeepbot/requirements.txt`

Additional platform-specific requirement files are also available in `src/jeepbot/`.

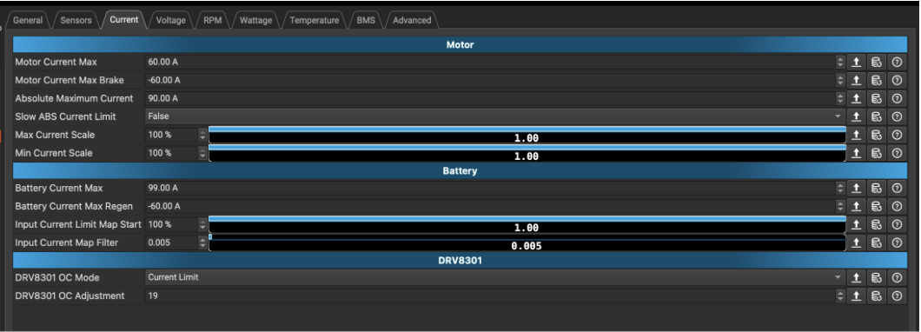
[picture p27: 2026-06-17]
docs/assets/setup2.png

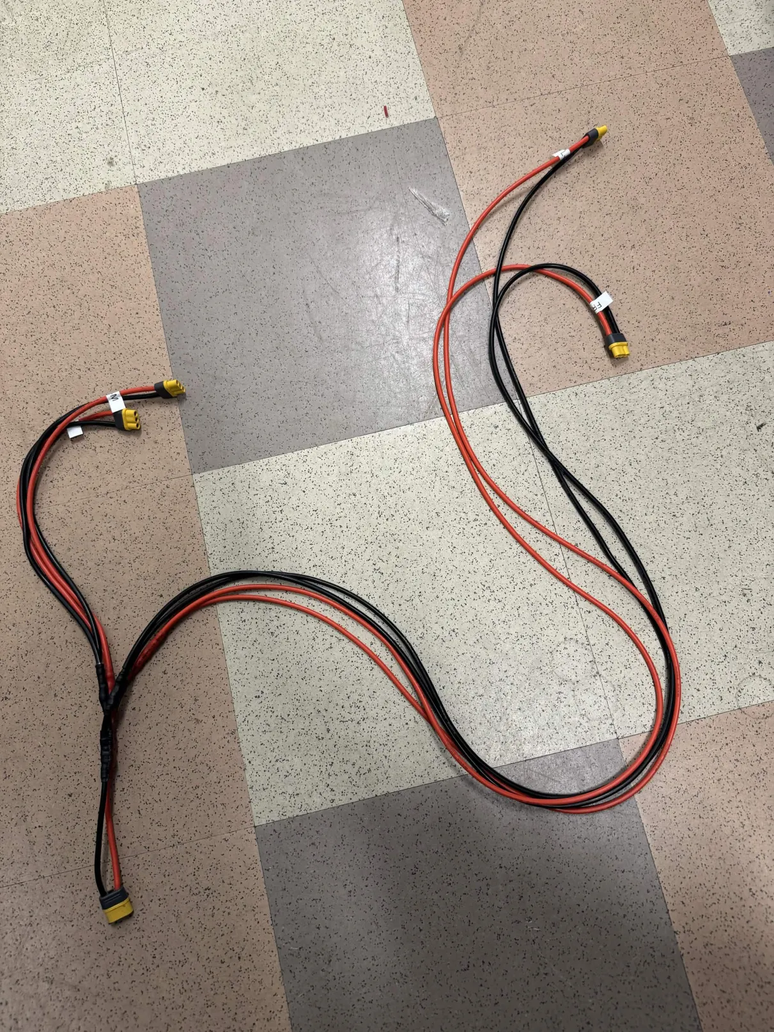
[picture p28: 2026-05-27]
docs/version2/media/photos/wiring/wiring_main_power_harness_layout.jpg

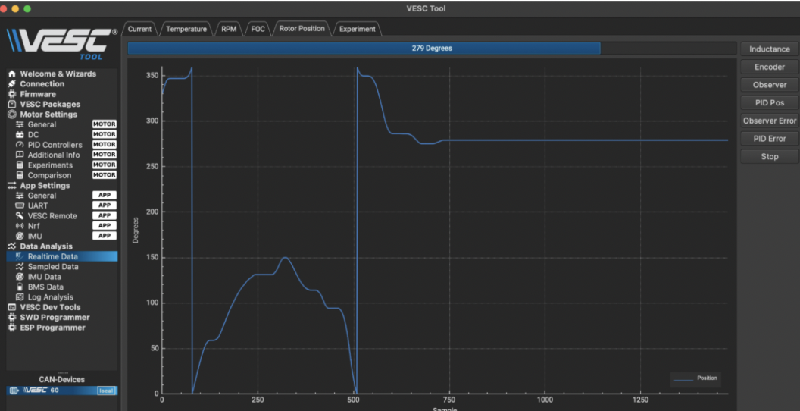
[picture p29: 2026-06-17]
docs/assets/setup5.png

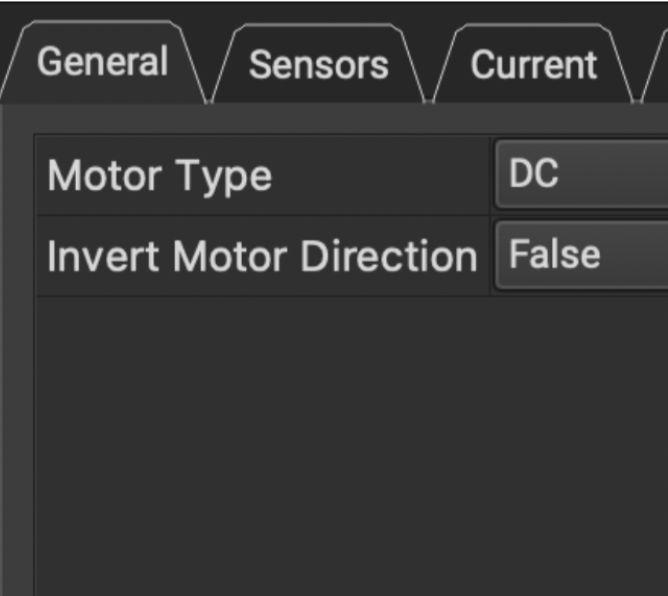
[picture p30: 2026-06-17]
docs/assets/setup1.png

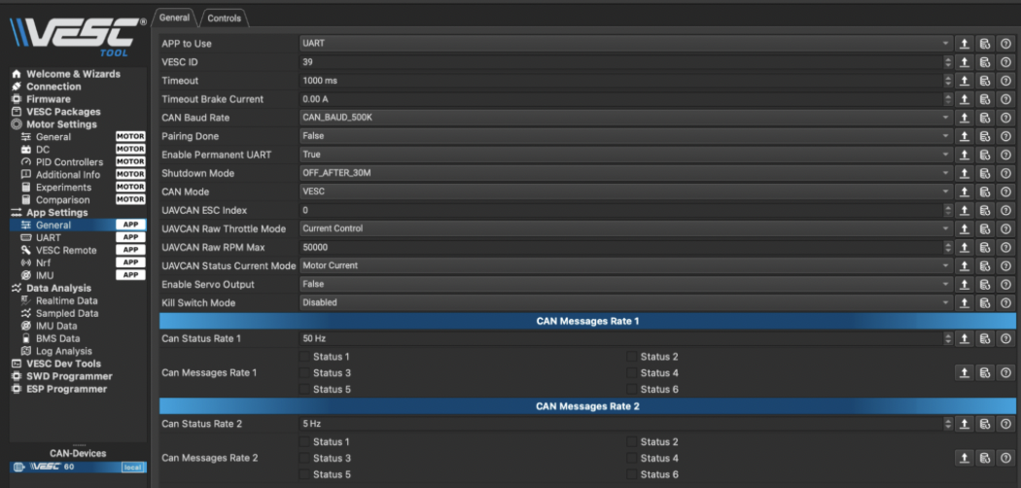
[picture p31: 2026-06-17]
docs/assets/setup4.png

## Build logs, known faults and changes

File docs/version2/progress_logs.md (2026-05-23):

## 1. Overview
This section tracks the progress of the project, including completed work, current status, and next steps.

It documents development over time and helps maintain alignment across the team.

---

## 2. Timeline of Progress

### April 16 — Meeting Notes

**Hardware Layout**
- Electronics positioned in front  
- Battery moved to front  
- Steering VESC in front  
- Motor VESC in back  

**System Architecture Change**
- Simplified from 5 VESCs → 2 VESCs  
  - 1 for steering  
  - 1 for drive  
- CAN multi-VESC system removed  

**Power System**
- Battery → antispark → system  
- Antispark used as main switch  

**Wiring**
- Routed front → back  
- Cable management required  
- Motor polarity must be verified  

**Emergency Stop**
- Placement not finalized  
- Must be accessible  

**Sensors**
- Current LiDAR acceptable  
- Future upgrade planned  

**Mechanical**
- Plan for modular mounting plate  
- Laser-cut design  
- Flexible layout  

---

### April 29 — Updates

- Schematics updated 
- Wiring requires significant work
- GitHub repository received positive feedback:
  - Past documents will be organized under **Version 1**  
  - A new **Version 2** will be created for updated work and ongoing progress  
- Team was asked to document progress with as many photos as possible this week for presentation purposes  

---

### April 30 — Updates

**Completed Work**
- Final laser cuts for electronics mounting plates completed
- First iteration of mechanical mounts 3D printed
- Feedback provided to MAP mechanical team for improvements
- GitHub repository reorganized:
  - Version 1 (past work)
  - Version 2 (current + ongoing work)
- Initial system documentation created (overview, hardware, software, etc.)
- Schematics updated based on recent discussions

---

### May 1 — Updates (Meeting)

- Emphasized the importance of consistently taking photos and documenting our work
- This will be useful for future classes and for the next group of students

---

### May 6 — Updates (Lab Work)

**System Architecture / PDB Changes**
- System updated from 2 PDBs → 4 PDB configuration
- Front PDB:
  - powers steering VESC
  - sends power to rear PDB
- Rear PDB distributes power to:
  - motor VESC
  - 24V → 5V DC-DC converter
  - 24V → 12V DC-DC converter

**Completed Work**
- Rear XT60 → XT60 PDB completed
- Front XT90 → XT60 PDB partially completed
- Front-to-back 10 AWG XT60M → XT60F power cable assembled
- Significant wire labeling completed

**Documentation**
- System schematic updated to reflect latest architecture
- Editable SharePoint schematic link updated
- GitHub documentation under version2 continues to be updated

**Outstanding Tasks**
- Acquire XT90 connector for front PDB input
- Build XT60 → XT30 PDBs for DC-DC converters
- Finalize EMO integration with the rest of the system
- Locate relay/current-handling component required for EMO implementation
- Continue documentation and progress photos

**Notes**
- Additional schematic review recommended before final wiring implementation

---

### May 8 — Updates (Meeting)

- Prof. Jack suggested checking with Corey for extra XT90 connectors before ordering new ones on Amazon
- Corey may already have pre-soldered XT90 connectors available
- Relay components should already be located in the team workbench according to Prof. Silberman
- Need to confirm the micro PDB splitter setup with Jose
- Current goal is to get the JeepBot physically running by Monday
- Goal for the next meeting is to achieve basic remote control functionality
- Additional support from another ECE/MAE 148 team will assist with the JeepBot project
- Possible meeting with the assisting 148 team planned for next week depending on availability

---

### May 14 — Updates (Lab Work)

- Multiple PDBs soldered and assembled
- Located the small XT60 → XT30 PDBs (green boards)
- Continued progress on wiring organization and power distribution setup
- Waiting for remaining fuses to arrive
- Waiting for 24V → 12V DC-DC converter
- T12 team has been helping significantly with the project

---

### May 22 — Sprint 2 Progress Report

**Completed Work**
- Learned how to use the encoder in VESC Tool and integrated it with PyVESC to control all motors through Python
- Soldered all PDBs and wires
- Set up OAK-D Pro to run with Python
- Completed a test drive
- Created a web documentation site covering the full JeepBot setup guide (VESC, Encoder, F710 Controller & Raspberry Pi)

**Lessons Learned**
- Configured encoder + motor to work as a servo
- Camera setup process
- Controlling 2 VESCs for driving and steering via PyVESC
- Used DonkeyCar as a reference for JeepBot implementation

**Challenges**
- OAK-D Pro camera gray screen issue encountered during setup
- Anti-spark troubleshooting required before finding a working configuration
- JeepBot currently controls correctly via controller but loses control when camera preview is open

**Components Needed**
- *Urgent:*
  - Long USB to Micro USB cable ×1 (to connect front VESC to Raspberry Pi)
  - Long USB to USB-C cable ×2 (to connect front camera data and power to Pi and hub)
- *For future:*
  - 10A Mini Blade Fuse
  - Fuse holder

---

## 3. Current Status

**Mechanical Mounts**
- First iteration completed and evaluated
- Waiting on updated designs from MAP team
- Electrical components not yet permanently mounted

**Wiring**
- All PDBs soldered and assembled
- Wiring cleanup in progress — goal is safe passenger boarding
- Anti-spark working after troubleshooting

**Software / Controls**
- VESC encoder integrated with PyVESC
- Motor control through Python operational
- OAK-D Pro camera set up with Python; gray screen issue under investigation
- Controller-based driving functional; camera preview causes loss of control (active issue)

**Documentation**
- Version 2 structure created and being actively updated
- Web documentation site live with full setup guide
- Schematics and wiring documentation updated

**System Architecture**
- Finalized around 2 VESC setup (drive + steering)
- Updated to 4 PDB power distribution layout

---

## 4. Next Steps

**Wiring & Hardware**
- Clean up all wiring for safe passenger boarding
- Mount all electrical components permanently
- Acquire urgent cables (USB to Micro USB ×1, USB to USB-C ×2)
- Acquire 10A Mini Blade Fuses and fuse holder

**Software & Perception**
- Set up object detection
- Implement obstacle detection and automatic stopping
- Resolve OAK-D Pro camera preview conflict with motor control

**Navigation (Planned)**
- GPS integration and waypoint planning (Week 1–2)
- Heading and motion controller (Week 2)
- OAK-D depth stream setup (Week 1)
- Obstacle detection and avoidance (Week 2)

**Integration & Testing (Planned)**
- System fusion and route definition (Week 3, May 23 – Jun 1)
- Outdoor test runs and tuning (Week 4, Jun 1–5)
- Final demo (Jun 5–7)

**Documentation**
- Continue updating GitHub (version2)
- Upload additional progress photos to GitHub (version2/media)

---

## 5. Key Challenges
*(Continuously updated)*

- OAK-D Pro camera gray screen issue
- JeepBot loses motor control when camera preview is active
- Wiring still needs cleanup and permanent mounting
- Missing urgent cables (USB to Micro USB, USB to USB-C)

---

## 6. Notes
*(Continuously updated)*

- Major issues and milestones should be recorded
- Continue documenting implementation progress with photos
- Web documentation site available — link accessible via QR code in Sprint 2 slides
- DonkeyCar used as implementation reference for PyVESC integration

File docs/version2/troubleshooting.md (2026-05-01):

# Troubleshooting

## Power Issues

- System not turning on:
  - Check battery voltage
  - Verify EMO is disengaged
  - Check antispark switch

- LiDAR not powering:
  - Inspect 12V DC-DC converter

## Compute Issues

- Raspberry Pi not booting:
  - Verify 5V rail output

## Motor Issues

- Motors not spinning:
  - Check VESC connections

## Wiring

- Inspect XT60 / MR60 connectors
- Check polarity

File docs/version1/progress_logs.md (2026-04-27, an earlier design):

## 1. Overview

This section tracks the progress of the project, including completed work, current status, and next steps.

It documents development over time and helps maintain alignment across the team.

---

## 2. Timeline of Progress

### March 9

- GitHub repository created and organized  
- System schematic work started  
- Initial research on teleoperation solutions  
- Planning for camera streaming on Raspberry Pi  

### March 11

- Focus on documenting hardware system  
- Wiring, connectors, and power system analyzed  
- Internal system components identified  
- Communication with team regarding missing components  

### March 17

- Structured project documentation created  
- Overview, hardware, and system architecture documented  
- Mechanical mounts documentation integrated  
- Setup, troubleshooting, and BOM sections started (WIP)  

### March 18

- Initial full-system test performed  
- Preparation for Phase 1 demo  
- Knowledge transfer initiated  
- RC controller operation documented  
- Codebase migrated to TritonAI repository  
- Future development path identified  

### March 20

**Hardware Integration**

- All major components mounted (Pi, cameras, LiDAR housing)  
- Battery installed under seat (XT90 routing)  

**Power System**

- Antispark switch broken (does not interrupt power)  
- System powers on immediately (unsafe)  
- PDB fuse missing/damaged (LiDAR inactive)  
- 5V DC-DC cables too short  
- Pi and USB hub not properly powered  

**Control & Communication**

- Raspberry Pi mounted with CAN HAT  
- CAN between VESCs functional  
- CAN not connected to Pi yet  
- VESCs tested individually  
- No full-system control implemented  

**Steering System**

- Steering VESC connected  
- Encoder not connected  
- Encoder incompatible with VESC  
- Steering non-functional  

**Sensors**

- Cameras mounted but not connected  
- Front camera needs longer cable  
- LiDAR not powered  
- GPS not available  

**Software**

- Raspberry Pi reflashed  
- Environment not verified  
- Control software not implemented  
- System not operational  

---

### April 16 — Meeting Notes

**Hardware Layout**

- Electronics positioned in front  
- Battery moved to front  
- Steering VESC in front  
- Motor VESC in back  

**System Architecture Change**

- Simplified from 5 VESCs → 2 VESCs  
- 1 for steering  
- 1 for drive  
- CAN multi-VESC system removed  

**Power System**

- Battery → antispark → system  
- Antispark used as main switch  

**Wiring**

- Routed front → back  
- Cable management required  
- Motor polarity must be verified  

**Emergency Stop**

- Placement not finalized  
- Must be accessible  

**Sensors**

- Current LiDAR acceptable  
- Future upgrade planned  

**Mechanical**

- Plan for modular mounting plate  
- Laser-cut design  
- Flexible layout  

---

## 3. Current Status

The project is in the hardware integration and system bring-up phase.

### Completed

- Mechanical system assembled  
- Wiring infrastructure implemented  
- VESCs tested individually  
- Encoders mounted  
- Raspberry Pi installed  
- Sensors mounted  
- Documentation structured  

### In Progress

- Software integration  
- Pi ↔ VESC communication  
- Teleoperation setup  
- Wiring cleanup  
- Sensor connectivity  

---

## 4. Next Steps

- Replace antispark switch  
- Fix PDB fuse (LiDAR power)  
- Complete 5V connections  
- Finish CAN wiring  
- Integrate steering encoder  
- Connect cameras and LiDAR  
- Configure Raspberry Pi software  
- Implement RC control via Pi  
- Validate full system  

---

## 5. Key Challenges

- Broken antispark (safety risk)  
- PDB fuse issue  
- No system movement  
- Steering not working  
- Incomplete wiring  
- No emergency stop  
- Software not ready  

---

## 6. Notes

- This section will be continuously updated  
- Major issues and milestones should be recorded

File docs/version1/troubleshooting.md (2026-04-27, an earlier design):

## Troubleshooting

This section provides troubleshooting guidelines based on the current system state. The system is still under development, so additional issues and solutions will be added over time.

---

## 1. Robot Not Moving

**Possible causes:**

- Raspberry Pi not integrated with VESC network  
- CAN communication not implemented  
- RC receiver not fully connected  
- Control software not running  
- Power not properly distributed  

**What to check:**

- Verify Raspberry Pi is powered and accessible  
- Confirm CAN wiring is connected to CAN HAT  
- Check that VESCs are powered  
- Verify RC controller and receiver are connected  
- Confirm control software is running  

---

## 2. No Power or Inconsistent Power

**Possible causes:**

- Antispark switch failure  
- Battery not properly connected  
- Damaged or missing PDB fuse  
- Loose XT connectors or wiring  
- 5V DC-DC not connected to Raspberry Pi  

**What to check:**

- Confirm battery connection  
- Inspect antispark behavior  
- Check PDB fuse status (especially LiDAR line)  
- Verify XT connectors and wiring  
- Confirm 5V output to Raspberry Pi and USB hub  

---

## 3. Cannot Connect to Raspberry Pi

**Possible causes:**

- Raspberry Pi not powered  
- Network configuration issues  
- Pi not properly set up after reflash  

**What to check:**

- Verify power to Raspberry Pi  
- Confirm network connection  
- Check SSH / NoMachine settings  
- Ensure Pi has completed boot  

---

## 4. Sensors Not Working

**Possible causes:**

- Sensors not connected to USB hub  
- USB cables too short or disconnected  
- LiDAR not powered  
- GPS not installed  

**What to check:**

- Verify camera connections  
- Check USB cables  
- Confirm LiDAR power  
- Verify USB hub power  
- Confirm GPS availability  

---

## 5. Steering Not Working

**Possible causes:**

- Steering encoder not connected  
- Encoder not compatible with VESC  
- No feedback signal  

**What to check:**

- Verify encoder wiring  
- Confirm compatibility  
- Check encoder connection  
- Validate steering VESC configuration  

---

## 6. CAN Communication Issues

**Possible causes:**

- CAN not connected to Raspberry Pi  
- Loose connections  
- Incorrect wiring (CAN High / Low)  
- CAN working only between VESCs  

**What to check:**

- Verify CAN wiring  
- Connect to CAN HAT  
- Confirm polarity (yellow = CAN High, green = CAN Low)  
- Check terminals and connections  

---

## 7. Safety Issues

If any of the following occur:

- Unexpected movement  
- Overheating  
- Unusual noise  
- Sparks or instability  

**Action:**

- Immediately disconnect battery  
- Do not rely on antispark switch  
- Emergency stop may not be connected  

---

## 8. Notes

- This guide reflects an incomplete system  
- Issues may change as development continues  
- More solutions will be added over time

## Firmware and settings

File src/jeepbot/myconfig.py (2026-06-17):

# ===============================================
# JEEPBOT CONFIG FILE
# ===============================================

# ===============================================
# CONTROLLER SELECTION
# ===============================================
from controller_profiles import resolve as _resolve_controller

CONTROLLER = "f710"

_ACTIVE_CONTROLLER = _resolve_controller(CONTROLLER)
# Substring used by the reader class to select the USB device by name.
CONTROLLER_DEVICE_NAME = _ACTIVE_CONTROLLER["device_name"]

# ===============================================
# Steering — VESC motor + encoder (SetPosition)
# Degrees map to encoder position, NOT servo PWM.
# ===============================================
DEFAULT_STEERING_PORT        = "/dev/ttyACM1"
DEFAULT_STEERING_AXIS        = _ACTIVE_CONTROLLER["steering_axis"]
DEFAULT_STEERING_CENTER_DEG  = -40.0
DEFAULT_STEERING_LEFT_DEG    = -80
DEFAULT_STEERING_RIGHT_DEG   = 0
DEFAULT_STEERING_WRAP_DEG    = 0.0
DEFAULT_STEERING_RAMP_DEG_PER_S = 280.0
DEFAULT_STEERING_MIN_STEP_DEG   = 0.8
DEFAULT_STEERING_SMOOTHING   = 0.03
DEFAULT_INVERT_STEERING      = _ACTIVE_CONTROLLER["invert_steering"]

# ===============================================
# Drive — VESC duty-cycle (4WD)
# ===============================================
DEFAULT_DRIVE_PORT           = "/dev/ttyACM0"
DEFAULT_DRIVE_AXIS           = _ACTIVE_CONTROLLER["drive_axis"]
DEFAULT_INVERT_DRIVE         = _ACTIVE_CONTROLLER["invert_drive"]
DEFAULT_MAX_DUTY             = 0.20
DEFAULT_DRIVE_RAMP_DUTY_PER_S = 0.35
DEFAULT_DRIVE_SMOOTHING      = 0.08
DEFAULT_DRIVE_BRAKE_CURRENT_A = 0.0

# ===============================================
# Controller / loop
# ===============================================
DEFAULT_DEADMAN_BUTTON       = _ACTIVE_CONTROLLER["deadman_button"]
DEFAULT_RATE_HZ              = 100.0
DEFAULT_BAUDRATE             = 115200
DEFAULT_DEADZONE             = _ACTIVE_CONTROLLER["deadzone"]
DEFAULT_EXPO                 = 0.35

# ===============================================
# Web server + OAK-D Pro camera
# Both run as in-process daemon threads.
# ===============================================
ENABLE_WEB_SERVER            = True
WEB_HOST                     = "0.0.0.0"
WEB_PORT                     = 8887
WEB_PORT_REAR = 8888
# Drive modes: manual | record | auto_steering | full_drive
DEFAULT_DRIVE_MODE           = "manual"

# ===============================================
# Camera toggles + resolution (front / rear independent)
# ===============================================

ENABLE_FRONT_CAMERA          = True
ENABLE_REAR_CAMERA           = True

# Capture (and stream) resolution per camera as (width, height).
# Common OAK-D sizes: (1920, 1080), (1280, 720), (640, 480).
FRONT_CAMERA_RESOLUTION      = (640, 480)
REAR_CAMERA_RESOLUTION       = (640, 480)

# front may come up as device 0 or 1. If front and rear are swapped, flip this:
SWAP_CAMERAS                 = True

# Most reliable across reboots: pin each role to a specific OAK-D serial (MxId).
# Leave both "" to use discovery order + SWAP_CAMERAS above. Serials are printed
# at startup ("[camera] Found N OAK device(s): [...]"), or list them with:
#   python3 -c "import depthai as dai; print([d.getMxId() for d in dai.Device.getAllAvailableDevices()])"
FRONT_CAMERA_MXID            = ""
REAR_CAMERA_MXID             = ""

# ===============================================
# YOLO detection overlay
# ===============================================
# Requires running with the YOLO virtualenv:
#   source /home/jeepbot/yolo-test/bin/activate
ENABLE_YOLO_DETECTION        = True
YOLO_MODEL_PATH              = "/home/jeepbot/yolo_demo/yolov8n.pt"
YOLO_IMGSZ                   = 320
YOLO_CONFIDENCE              = 0.25
YOLO_INTERVAL_S              = 0.20

# Estimate object distance by sampling the aligned OAK-D stereo depth map
# inside each YOLO box. Depth values are millimeters.
ENABLE_DEPTH_DISTANCE        = True
DEPTH_MIN_MM                 = 150
DEPTH_MAX_MM                 = 10000
DEPTH_ROI_SCALE              = 0.35

# ===============================================
# Autonomous driving
# ===============================================
# Path to trained Keras model for auto_steering / full_drive.
# Set to None (or a non-existent path) to disable AI modes.
DEFAULT_MODEL_PATH           = "models/jeep_pilot.keras"

# Root directory for tub recordings (sub-folders created per session).
DEFAULT_TUB_PATH             = "tub"


# ===============================================
# Start JeepBot from terminal
#   python3 myconfig.py drive
# ===============================================
if __name__ == "__main__":
    import sys
    from jeepbot_drive import drive

    if len(sys.argv) < 2:
        print("Usage: python3 myconfig.py drive")
        raise SystemExit(1)

    command = sys.argv[1]
    sys.argv.pop(1)

    if command == "drive":
        drive(config=sys.modules[__name__])
    else:
        print(f"Unknown command: {command}")
        print("Use: python3 myconfig.py drive")

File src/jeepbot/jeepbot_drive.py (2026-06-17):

"""
JeepBot drive loop — dual VESC (motor+encoder steering, duty-cycle drive)
Integrates OAK-D Pro camera + Flask web server as in-process threads.

Drive modes (set via web UI or web_server.get_mode()):
  manual        — F710 joystick controls everything
  record        — joystick controls + tub data is recorded to disk
  auto_steering — AI steers, joystick controls throttle
  full_drive    — AI steers AND drives (full autonomous)
"""
from __future__ import annotations

import argparse
import math
import queue
import time
import threading
import serial
import sys

from serial.tools import list_ports

from pyvesc.protocol.interface import encode
from pyvesc.VESC.messages.setters import (
    Alive,
    SetCurrentBrake,
    SetDutyCycle,
    SetPosition,
)
from pygame_f710 import F710DirectInput
from pygame_radiomaster import RadioMasterInput
from web_server import JeepBotWebServer, JeepBotRearWebServer
from camera import start_camera_thread, start_rear_camera_thread, resolve_devices
# -----------------------------------------------------------------------
# Math helpers
# -----------------------------------------------------------------------

def clamp(value: float, low: float, high: float) -> float:
    return max(low, min(high, value))


def apply_deadzone(value: float, deadzone: float) -> float:
    if abs(value) <= deadzone:
        return 0.0
    sign = 1.0 if value > 0.0 else -1.0
    return sign * ((abs(value) - deadzone) / (1.0 - deadzone))


def shape_axis(value: float, expo: float) -> float:
    expo = clamp(expo, 0.0, 1.0)
    return ((1.0 - expo) * value) + (expo * math.copysign(value * value, value))


def wrap_degrees(value: float, wrap_deg: float) -> float:
    if wrap_deg <= 0:
        return value
    return value % wrap_deg


def shortest_wrapped_delta(start_deg: float, end_deg: float, wrap_deg: float) -> float:
    if wrap_deg <= 0:
        return end_deg - start_deg
    return ((end_deg - start_deg + (wrap_deg / 2.0)) % wrap_deg) - (wrap_deg / 2.0)


def endpoint_target_deg(
    stick: float,
    center_deg: float,
    left_deg: float,
    right_deg: float,
    wrap_deg: float,
) -> float:
    if stick < 0.0:
        delta = shortest_wrapped_delta(center_deg, left_deg, wrap_deg)
        target = center_deg + (-stick * delta)
    else:
        delta = shortest_wrapped_delta(center_deg, right_deg, wrap_deg)
        target = center_deg + (stick * delta)
    return wrap_degrees(target, wrap_deg)


def move_toward(current: float, target: float, max_step: float) -> float:
    error = target - current
    if abs(error) <= max_step:
        return target
    return current + (max_step if error > 0.0 else -max_step)


def move_angle_toward(
    current: float,
    target: float,
    max_step: float,
    wrap_deg: float,
    min_step: float,
) -> float:
    error = shortest_wrapped_delta(current, target, wrap_deg)
    if abs(error) <= max_step:
        return target
    step = max_step
    if min_step > 0.0:
        step = max(step, min(min_step, abs(error)))
    current += step if error > 0.0 else -step
    return wrap_degrees(current, wrap_deg)


# -----------------------------------------------------------------------
# Steering normalisation helpers (used for AI pilot output)
# -----------------------------------------------------------------------

def norm_to_deg(norm: float, config) -> float:
    """Convert [-1, +1] pilot output → steering degrees for VESC."""
    center = config.DEFAULT_STEERING_CENTER_DEG
    left   = config.DEFAULT_STEERING_LEFT_DEG
    right  = config.DEFAULT_STEERING_RIGHT_DEG
    norm   = clamp(norm, -1.0, 1.0)
    if norm <= 0.0:
        return center + (norm * (center - left))   # norm=-1 → left
    else:
        return center + (norm * (right - center))  # norm=+1 → right


# -----------------------------------------------------------------------
# Serial helpers
# -----------------------------------------------------------------------

def list_serial_ports() -> None:
    ports = list(list_ports.comports())
    if not ports:
        print("No serial ports found.")
        return
    for port in ports:
        print(f"{port.device}: {port.description}")


def open_serial(port: str, baudrate: int, label: str) -> serial.Serial:
    try:
        serial_port = serial.Serial(port, baudrate, timeout=0)
    except serial.SerialException as exc:
        raise SystemExit(
            f"Could not open {label} port {port}: {exc}\n"
            "Close VESC Tool or any other program using that serial port."
        ) from exc
    print(f"Opened {label} VESC serial port {port} at {baudrate} baud.")
    return serial_port


# -----------------------------------------------------------------------
# Argument parsing
# -----------------------------------------------------------------------
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

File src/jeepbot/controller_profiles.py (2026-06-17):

# ===============================================
# CONTROLLER PROFILES
# Per-controller axis/button/tuning maps, kept out of myconfig.py so the
# config file stays short. myconfig.py picks a name (CONTROLLER = "...") and
# calls resolve() to pull the matching values.
#
# Axis/button indices come from each device's HID layout and are NOT the same
# between controllers. To find them: run
#   python3 controller_axes_test.py
# wiggle one control, and read off the index that changes.
#
# device_name is a case-insensitive substring used to grab the right USB
# device when more than one joystick is plugged in. Leave "" to just use the
# first joystick found (fine when only one controller is connected).
# ===============================================

CONTROLLER_PROFILES = {
    "f710": {
        "device_name":     "",      # F710 dongle is usually the only joystick
        "steering_axis":   2,       # right-stick X (D mode)
        "drive_axis":      1,       # left-stick Y
        "deadman_button":  5,       # right bumper
        "deadzone":        0.08,
        "invert_steering": False,
        "invert_drive":    True,
    },
    "radiomaster": {
        "device_name":     "Arduino",   # Leonardo enumerates as "Arduino ..."
        # ---- CONFIRM THESE TWO WITH controller_axes_test.py ----
        # Wiggle the STEERING control -> note which axis moves -> set it here.
        "steering_axis":   0,       # TODO verify (X / channel 3 in the sketch)
        # Wiggle the THROTTLE control -> note which axis moves -> set it here.
        # NOTE: a mode-2 throttle stick does NOT self-center, so it won't rest
        # at 0 = stop. If you want spring-to-stop behaviour, pick a
        # self-centering stick axis instead, and lean on the deadman button.
        "drive_axis":      1,       # TODO verify (Y / channel 2 in the sketch)
        "deadman_button":  0,       # LBtn on the Leonardo (button 0)
        "deadzone":        0.10,    # bumped up: SBUS center isn't exactly 0
        "invert_steering": False,
        "invert_drive":    False,
    },
}


def resolve(controller: str) -> dict:
    """Return the profile dict for `controller`, or raise if it's unknown."""
    if controller not in CONTROLLER_PROFILES:
        raise ValueError(
            f"CONTROLLER={controller!r} must be one of {list(CONTROLLER_PROFILES)}"
        )
    return CONTROLLER_PROFILES[controller]

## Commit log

2026-04-19 Create Mounting Plates
2026-04-19 Create mounts
2026-04-27 Enhance documentation with new sections
    Added new sections for Media, Bill of Materials, and Progress & Logs to the documentation overview.
2026-04-27 Revise system schematic for clarity and detail
    Updated the system schematic to include detailed sections on power, computing, motor control, communication, emergency stop, and radio control systems.
2026-04-27 Add current status documentation for the system
    Document the current status of the system, including working components, issues with power, control, steering, sensors, wiring, safety, and software.
2026-04-27 Enhance hardware documentation with detailed sections
    Expanded hardware documentation to include detailed sections on architecture, power systems, wiring, connectors, and safety practices.
2026-04-27 Add mechanical system documentation for robot
    Added detailed documentation for the mechanical system of the robot, including mounts for sensors and installation instructions.
2026-04-27 Revise software architecture documentation
    Expanded software architecture documentation with detailed sections on control flow, teleoperation methods, sensor data handling, system operation, and future development plans.
2026-04-27 Add initial setup guide for the robot system
    This guide outlines the current setup status, limitations, and required steps for the system, which is not fully operational.
2026-04-27 Add bill of materials documentation for robot system
    Documented the bill of materials (BOM) for the robot system, including core components, sensors, wiring, and notes on integration.
2026-04-27 Add project progress documentation
    This document tracks the project's progress, including completed tasks, current status, and next steps. It includes detailed timelines, challenges, and notes for ongoing development.
2026-04-27 Revise project overview and current status in README
    Updated README to reflect current project status and next steps.
2026-04-27 Rename Jeepbot Photos/Wiring/Wiring - Underneath.jpeg to docs/media/photos/wiring-underneath.jpeg
2026-04-27 mounts pdf in media
2026-04-27 move to power
2026-04-30 Create new file inside docs to maintain new schematics
2026-04-30 Add version 1 of the bill of materials document
2026-04-30 schematic version2
2026-04-30 add schematic version 2
2026-04-30 Add progress logs documentation
    This document tracks project progress, including completed work, current status, and next steps. It includes meeting notes, updates, and key challenges.
2026-04-30 add photos of wires
2026-05-01 add wires
2026-05-01 add wires to overview
2026-05-01 add wire
2026-05-01 Refactor repo: clean CAD structure, standardize naming, improve setup and docs
    [DUAL MOUNT - CAMERA AND PDB.f3d, Encoder Mount.f3d, FRONT CAMERA CAP.f3d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]
2026-05-01 Add rear camera CAD folders to sensors and standardize naming
    [REAR CAMERA MOUNT.f3d, RIDGE MOUNT.f3d, Rear Camera Assembly.f3z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]
2026-05-01 Update progress logs with April 30 updates, current status, and next steps
2026-05-01 Revise progress logs for April 30 updates
    Updated progress logs to reflect current status, next steps, key challenges, and notes.
2026-05-01 Fix wire gauge notation in progress logs
    Corrected the wire gauge notation from '12AWG' to '12 GA' for clarity.
2026-05-01 Clean schematics structure, add README, and link interactive schematic
2026-05-01 Add interactive schematic link to system_schematic.md
2026-05-01 Add version1 schematic structure with interactive link
2026-05-01 Clarify wiring implementation details in progress logs
2026-05-07 Fix SharePoint link for interactive schematic
    Updated the link for the editable schematic in SharePoint.
2026-05-07 Fix link formatting in system schematic document
2026-05-07 Update SharePoint link for editable schematic
2026-05-16 Add May 14 updates to progress logs
    Added updates for lab work on May 14, including progress on PDBs and wiring organization.
2026-05-16 Add schematic with components to documentation
